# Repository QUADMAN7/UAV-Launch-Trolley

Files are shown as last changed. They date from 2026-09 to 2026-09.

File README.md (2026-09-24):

# IoT-Enabled UAV Launch Trolley


## Project Overview & Goal
This repository details the development of an automated ground support trolley engineered to launch gearless, fixed-wing Unmanned Aerial Vehicles (UAVs). The project originated from an operational constraint encountered on a custom aircraft I designed and manufactured in a previous project. Design trade-offs on that airframe resulted in higher wing loading than originally intended, requiring the 2.43 kg aircraft to achieve a high take-off airspeed of at least 18 m/s. Because the airframe utilizes a rear-pusher configuration spinning a large 13-inch propeller, hand launching was off-the-table due to the risk of propeller strikes to the operator and low-speed stalls. To eliminate these operational risks without adding parasitic weight or landing gear to the airframe itself, I engineered a launch trolley capable of safely accelerating the UAV to speed and actively dropping away the moment aerodynamic lift is achieved.

---
## System Architecture & Hardware
### Technical Specifications

| Subsystem | Component / Technology | Operational Role |
| :--- | :--- | :--- |
| **Control Unit** | ESP32 (Wi-Fi AP mode) | Real-time sensor polling, telemetry hosting, servo actuation |
| **Velocity Sensing** | Neodymium Magnet + Hall Effect Sensor | Wheel RPM, instantaneous velocity, distance, acceleration |
| **Arming Controls** | Toggle Switch / LED | Master safety arming input and visual status feedback |
| **Liftoff Detection** | Pad Limit Switch | Instantaneous weight-off-wheels trigger |
| **Clearance System** | Servo-latch + Rubber-tension Parallel Linkage | Folds support arms flat to allow clearance for 13" pusher prop |
| **Telemetry Interface** | ESP32 Access Point + Embedded Web Server | Live Web UI streaming speed and state data over Wi-Fi |

---

### Design and Iterations
To establish the optimal launch method for the aircraft, I began by conducting a trade-off study across several concept architectures. I evaluated bungee systems, launch rails, catapults, and various airframe-mounted landing gear options, including both fixed and jettison-able assemblies. Ultimately, I eliminated catapults, rails, and onboard landing gear because they either imposed weight and drag penalties on the airframe—which directly inflated the required take-off velocity—or introduced high mechanical complexity with an elevated risk of damaging the aircraft during separation. Selecting an external ground support trolley provided the best solution: it added zero flight mass to the aircraft, offered reusable launch capabilities without airframe fatigue, and delivered a simple, robust footprint for field operations.

The cart chassis was designed to use easily machinable materials. A structural plywood plank acts as the base to which everything is mounted. Atop this base is a parallel-motion linkage engineered to drop the airframe support cradles instantly upon lift-off. To ensure the linkage folds flat with minimal mechanical resistance, I integrated ball bearings into all primary pivot joints to eliminate binding. The linkage is held in its elevated position by a servo-operated claw controlled by the ESP32. Upon receiving a release command, the servo disengages the claw, allowing a pre-tensioned rubber band to snap the mechanism flat. Using an elastomeric element provided a rapid, high-reliability restoring force without the weight, complexity, or power draw of active motorized retraction. To maximize stability during ground roll, the cradle pads were custom-designed as exact negative moulds of the aircraft's lower fuselage, ensuring a snug, load-distributing fit.

Beneath the main chassis, the running gear consists of dual axles supported by four low-friction bearing blocks. Sizing the wheels required a careful balance between ground clearance and roll stability: they needed to be large enough to roll over runway imperfections, yet compact enough to keep the overall centre of gravity low and prevent tipping instabilities during high-speed acceleration on the take-off run. During the initial design phase, I considered adding an active steering system linked directly to the aircraft’s rudder control channel, however, after analysing the failure modes and mass budget, I chose to omit ground steering. Eliminating active steering hardware simplified the system architecture and saved critical weight whilst accepting the trade-off that an unsteerable cart is susceptible to heading drift due to runway bumps and differential wheel rolling resistance. That said, I made the optimistic assumption that the aircraft's rudder would provide sufficient control authority for straight tracking on adequately smooth runway surfaces.

---

### How It Was Built
The trolley was constructed using a hybrid material selection composed of 12mm plywood, 3D-printed PLA, flexible TPU, and lightweight 8mm aluminium tubing. A 12mm plywood board forms the chassis, serving as a flat, rigid structural base to anchor all mechanical linkages, axle blocks, and electronic subassemblies.

The majority of the functional components—including the parallel-motion linkage arms, wheel hubs, and bearing housings were additively manufactured using PLA. While PETG offers higher impact resistance, limitations of my 3D printer (specifically thermal warping on larger geometries) made PLA the more reliable choice for maintaining tight dimensional tolerances across the joint linkages. To complement the rigid PLA parts, flexible TPU was strategically applied where compliance and energy absorption were necessary. TPU was used for the tyres to dampen runway vibrations, for the bump-stop that catches the linkage when it snaps flat, and for the airframe support pads that conform to the aircraft's fuselage.

To span the support footprint of the aircraft without adding unnecessary rotating mass or printing oversized plastic parts, I used 8mm aluminium tubing for both the axles and the upper cradle support frame. Utilizing aluminium tubes provided a significantly stiffer, lighter, and simpler structural bridge than attempting to 3D print a massive PLA/TPU equivalent. The custom-moulded TPU support pads were permanently bonded to the 8mm aluminium bars using epoxy resin. The entire mechanical assembly is secured using M3 hardware, integrating heat-set brass inserts directly into the 3D-printed components to deliver robust, reusable threaded joints that withstand repeated operational loads.

Before final physical assembly, the embedded control hardware and sensor circuits were prototyped and validated on a breadboard. This allowed me to make sure everything worked as intended prior to mounting it all to the trolley.

---

### Electronics
To govern the real-time telemetry, safety interlocks, and mechanical release, the trolley utilizes a custom embedded system centred around an ESP32 microcontroller. Power management is handled by an onboard 9V battery paired with a DC-DC buck converter, stepping the voltage down to a regulated 5V rail to reliably power the microcontroller, sensors, and actuation hardware.

The sensing suite consists of two primary inputs designed to feed the onboard kinematics and state tracking logic. A Hall effect sensor tracks wheel rotations to calculate real-time ground speed, while a physical limit switch embedded beneath the support pads acts as a weight-off-wheels sensor to confirm whether the aircraft is actively sitting on the trolley or not. System actuation is intentionally streamlined to minimize power draw and weight, relying on a single analogue servo. When triggered by the ESP32's safety logic, this servo disengages the latching mechanism, allowing the parallel-motion linkage to collapse flat under the tension provided by the rubber band.

For field operation and ground crew safety, the human-machine interface incorporates a heavy-duty mechanical arming toggle switch, a visual status LED, and an audible piezo buzzer. Recognizing that bright outdoor sunlight and high-glare field environments can easily obscure visual LED feedback during launch operations, I integrated a buzzer that provides unambiguous audible confirmation when the trolley is armed. This dual-sensory confirmation guarantees that ground operators can definitively verify the system's state before initiating a high-speed take-off run.

---

### Firmware & Embedded Systems Overview

* **Non-Blocking Speed Tracking:** Uses hardware interrupts to measure microsecond pulse intervals from the Hall effect sensor. Speed calculations are mathematically filtered to minimise sensor noise, with a 0.5 second timeout to automatically clear stale speed readings when coming to a stop.
* **Off-Grid Telemetry Web Dashboard:** The ESP32 broadcasts a local Wi-Fi signal hosting a live HTML interface. Ground crew can connect via smartphone to view live speed, acceleration, and take-off distance without relying on external internet or ground control stations.
* **Fail-Safe Release Interlock:** To prevent accidental drops, the parallel linkage release servo will only trigger when three independent conditions are met simultaneously:
  1. The master arming switch is flipped ON (confirmed via status LED and audible buzzer).
  2. The cart reaches or exceeds the target 18m/s take-off speed threshold.
  3. The aircraft lifts off, un-weighting the cradle's physical limit switch.

> **Full Firmware Breakdown:** For a complete look at the state machines, filtering logic, and code structure, see the [Firmware Architecture Documentation](Firmware/README.md).

---

### Operational Flow Diagram

```text
[ Ground Acceleration Phase ]
  │  ├── Hall sensor measures wheel RPM -> ESP32 calculates velocity
  │  └── ESP32 streams live velocity, displacement and acceleration data to Web UI over Wi-Fi
  ▼
[ Lift-off Event (V_ground ≥ 18 m/s) ]
  │  ├── Aerodynamic lift removes 2.43 kg weight from cradle
  │  └── Support pad limit switch is in normally open position (Weight-Off-Wheels signal)
  ▼
[ Active Clearance Trigger ]
  │  ├── ESP32 receives limit switch signal
  │  ├── Release servo disengages support arm latch
  │  └── Rubber band folds linkages flat
  ▼
[ Safe Separation ]
     └── 13" pusher prop passes cleanly over folded cart
```
---
## Engineering Challenges & Solutions
**1. 13" Propeller Clearance:** After making many iterative sketches, I found that the most suitable way to solve the issue was to increase the clearance between the trolley and the UAV at the point of take-off. This solution offered a package that was smaller and, consequently, lighter than other ideas I explored. This has the benefit of being easier to transport and for the UAV to accelerate itself and the trolley more quickly (therefore using less runway). To come up with a system to increase the clearance between the UAV and the trolley support pads upon which the UAV sits, I researched different mechanical systems such as scissor lifts but decided to go with a parallel motion linkage as it was simpler and could quickly be actuated to go from its highest point to its lowest point.

**2. Sensor Saturation:** In my initial design of the wheel speed tracking system, I embedded eight evenly spaced neodymium magnets into the wheel hub to maximize velocity measurement resolution. During high-speed testing, however, I discovered that this high-density arrangement only functioned reliably at low speeds under 5 m/s. Beyond this threshold, the rapid rotational frequency overwhelmed the Hall effect sensor's frequency response. The sensor could no longer react quickly enough to detect the magnetic gaps between pulses, causing it to saturate and latch into a continuous detection state.

This physical saturation directly interacted with my firmware's safety logic. To prevent the system from holding a stale speed reading after coming to a complete stop, I had programmed a timeout mechanism that reset the calculated velocity to 0 m/s if no pulse interrupts were registered within a set time window. Consequently, when sensor saturation occurred at speed, the lack of toggling state transitions caused the code to interpret the continuous signal as a stopped cart, abruptly dropping the telemetry speed output to 0 m/s mid-run.

To resolve this sensor bandwidth issue, I modified the wheel hub to house only a single neodymium magnet, lowering the pulse frequency enough in the hopes that it would be able to accommodate take-off velocities up to 25 m/s. While this change successfully restored function for standard testing, a critical evaluation of the system suggests that at the higher end of the operational envelope (exceeding 15 to 18 m/s) the sensor may approach its hardware response limits once again due to the high RPM of the small wheels.

In evaluating future design iterations to eliminate this failure mode entirely, I analysed two potential engineering solutions. The first option—increasing the main wheel diameter to lower the rotational RPM—was ruled out because a larger wheel elevates the cart's centre of gravity, significantly increasing the risk of dynamic tip-over during high-speed acceleration runs. The superior engineering approach would be to integrate a secondary sensor wheel connected to the main axle via a mechanical gear reduction. This would allow the magnets to pass the Hall effect sensor at a lower, controlled frequency during high-speed runs while maintaining a low centre of gravity and preserving full signal integrity across the entire operational envelope.

**3. Premature Retraction**: I implemented a triple-condition safety interlock in the state machine logic in order to avoid a scenario where a bump on a runway causes the UAV to momentarily lift-off the support pads at low airspeeds, tricking the microcontroller into thinking the UAV has taken-off, leading to a high-speed prop strike while the drone was still on the cart, potentially damaging the UAV as well as the cart. The ESP32 strictly forbids servo actuation unless three conditions are met simultaneously:
  1. **Master Arm Switch:** The arm switch must be toggled ON. This also has the benefit of allowing you to setup the UAV on the cart without worrying that the cart might fold whilst on the bench
  2. **Weight-Off-Wheels Signal:** Limit switch state registers open.
  3. **Velocity Threshold Interlock:** Real-time Hall sensor speed readout confirms $V_{\text{ground}} \ge 18\text{ m/s}$ alongside a 100ms debouncing window.

---

## Conclusion
This instrumented ground support trolley successfully bridges the gap between high-speed aerodynamic constraints and safe launch logistics. By combining embedded C++ firmware, Hall-effect sensing, and active mechanical clearance linkages, the system replaces high-risk hand launches with a repeatable, telemetry-monitored ground take-off platform.

Although designed around a specific 2.43 kg fixed-wing SAR airframe, the modular mechatronic architecture serves as a scalable foundation for future Ground Support Equipment across higher-weight unmanned systems.

---
## Repository structure
```text

├── CAD/
│   └── Launch Trolley.step     # Full mechanical cart assembly
│
├── Firmware/
│   ├── Complete_System.ino     # Code
│   └── README.md     # Deep dive into code
│
├── Media/
│   └── README.md     # Pictures and renders of final product and iterative sketches
│
└── README.md
```

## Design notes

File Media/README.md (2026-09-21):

### This file contains pictures of Sketches, renders, the final product and a showcase of the web interface hosted by the ESP32




Launch_Trolley_2026-Sep-07_11-09-02AM-000_CustomizedView33224193533
Launch_Trolley_2026-Sep-07_11-10-29AM-000_CustomizedView13705926072
Launch_Trolley_2026-Sep-07_11-12-04AM-000_CustomizedView38185863168











### Showcase of Web interface hosted by the ESP32
https://github.com/user-attachments/assets/f3720539-ddbf-49d7-8c27-fad475daf408

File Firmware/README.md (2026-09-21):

# Firmware Architecture & Control Logic

## 1. System Intent & Engineering Strategy
The primary function of the trolley firmware is to provide real-time launch telemetry and govern the automated release mechanism for the UAV. To ensure safe, reliable operations in field environments, the software architecture was designed around three core principles:

1. **Non-blocking Telemetry:** Measure vehicle speed, displacement, and acceleration continuously without stopping the main control loop.
2. **Fail-Safe Safety Interlocks:** Prevent premature mechanical actuation through a combination of physical hardware states and firmware logic gates.
3. **Zero-Infrastructure Monitoring:** Broadcast live flight metrics directly to operators without relying on external Wi-Fi networks or bulky ground control equipment.

---

## 2. Telemetry & Signal Processing

### Interrupt-Driven Kinematics
To capture high-speed wheel rotations accurately, wheel pulse detection is handled via hardware interrupts (`IRAM_ATTR`). Measuring microsecond intervals (`micros()`) between pulse triggers provides higher accuracy than polling the pin in the main loop.

### Noise Mitigation & Filtering
Raw velocity calculations from small-diameter wheels are inherently prone to mechanical vibration and pulse jitter. To deliver stable control inputs and clean UI visualization, the firmware processes raw sensor signals through two stages:

* **Exponential Moving Average (EMA) Filter:** Smooths transient velocity spikes using a weighting factor ($\alpha = 0.2$). This prioritizes trend stability while retaining low latency for rapid acceleration runs.
* **Dynamic Clamping:** Physical acceleration values are clamped within physical bounds ($\pm 20\text{ m/s}^2$) to eliminate erroneous mathematical noise spikes during rapid signal state changes.
* **Zero-Speed Timeout:** To prevent stale telemetry output when the trolley stops, a $0.5\text{-second}$ pulse timeout automatically resets velocity to zero if no new magnet pulses are registered.

---

## 3. Safety Interlocks & Release State Machine

Accidental release of the parallel linkage during pre-flight handling poses a direct hazard to the airframe and ground crew. To eliminate single-point failures, mechanical release requires three independent conditions to be satisfied simultaneously:
``` text
[ Hardware Arm Switch: ON ] ──┐
├─► [ Logical AND Gate ] ──► [ Command Servo Release ]
[ Weight-Off-Wheels: HIGH ]  ──┤
│
[ Launch Speed >= 18 m/s ]   ──┘
```

1. **Master Physical Arming Switch:** Mechanically isolates the system. When disarmed, the servo is held rigidly at $190^\circ$ (latching the linkage), regardless of sensor inputs.
2. **Audible & Visual State Feedback:** Upon arming, the ESP32 drives an LED and fires a piezo buzzer tone to alert field operators.
3. **Automated Velocity Threshold:** The release servo ($0^\circ$) will only trigger once smoothed ground velocity meets or exceeds the minimum flight speed ($18\text{ m/s}$) AND the weight-off-wheels sensor indicates the aircraft is lifting.

Upon successful release, the firmware latches the current displacement value to permanently record the total ground roll distance required for take-off.

---

## 4. Off-Grid Field User Interface
To eliminate the need for heavy ground station laptops, the ESP32 acts as a standalone Wi-Fi network hosting a HTTP web server. 

* The server delivers a single lightweight HTML/JS dashboard to connected mobile devices.
* Kinematic state data (`displacement`, `velocity`, `acceleration`, `takeOffDistance`) are packaged as lightweight JSON text and served at a `/data` web address that the browser reads automatically
* Client-side JavaScript polls this endpoint asynchronously every $200\text{ ms}$, delivering real-time numerical visual readouts without triggering full page reloads.

---

## 5. Prototype Trade-Offs & Production Enhancements

As an initial functional prototype, the system successfully validated automated launch mechanics in bench testing. For future production iterations, before conducting a real world test, the following software enhancements are planned:

* **Non-Volatile Logging:** Integrate SD card logging to store historical run data locally for post-flight telemetry analysis.
* **Dynamic Speed Calibration:** Allow operators to adjust the threshold launch speed directly from the web interface prior to arming, eliminating the need to re-flash firmware for different airframes.

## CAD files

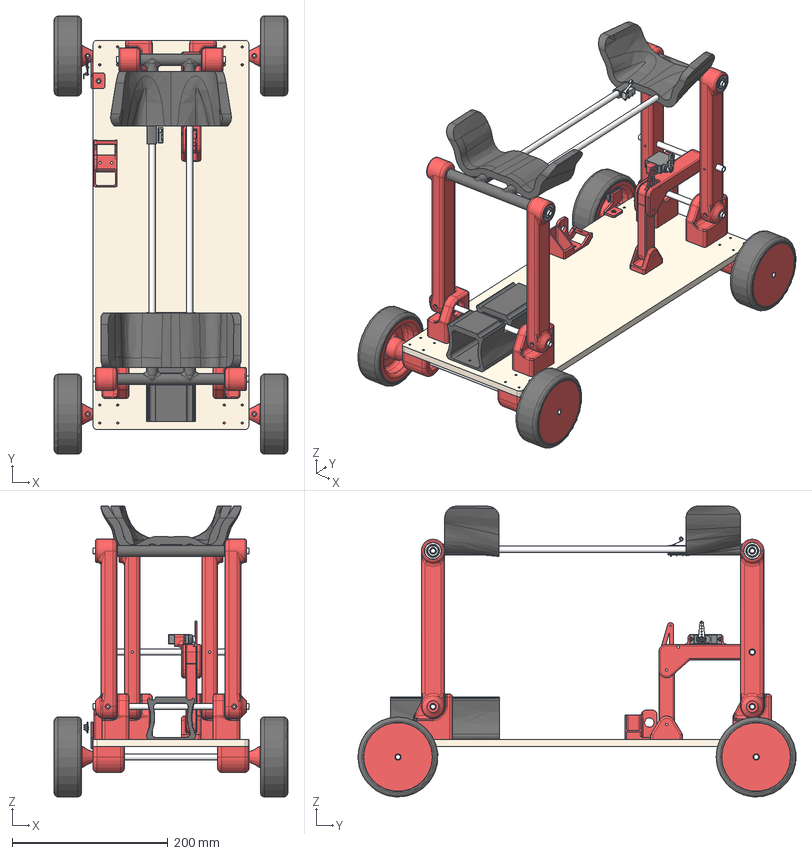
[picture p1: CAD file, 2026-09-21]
CAD/Launch Trolley.step
300.0 x 562.5 x 373.4 mm
Interface
2349K701_Permanently Lubricated Ball Bearing x 10
Arm 1
Base 1
Arm 2
Base 2
Arm 3
Base 3
Arm 4
Base 4
Aluminium Rod [R] (1)
Base
Servo Mount (1)
Claw
Wheels
2349K701_Permanently Lubricated Ball Bearing(Mirror)
7658K16_Subminiature Snap-Acting Switch
92095A287_Button Head Hex Drive Screw(Mirror)
Arm(Mirror)
9SENHMS
Hall Effect Sensor Mount
Switch Mount+Battery Tray

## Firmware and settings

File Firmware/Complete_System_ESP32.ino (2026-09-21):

#include <WiFi.h>
#include <WebServer.h>
#include <ESP32Servo.h>

// Hardware config
#define HALL_SENSOR_PIN 20  // Hall sensor pin
#define ARM_SWITCH_PIN 9    // Arm switch
#define ARM_LED_PIN 4       // Arm LED
#define BUTTON_PIN 5        // Momentary switch
#define SERVO_PIN 7         // Servo signal

const uint8_t NUM_MAGNETS = 1;
const float WHEEL_RADIUS = 0.1027 / 2.0; // meters
const float CIRCUMFERENCE = 2.0 * PI * WHEEL_RADIUS;

volatile unsigned long lastTime = 0;
volatile unsigned long period = 0;
volatile int hallCounter = 0;

float velocity = 0.0;
float displacement = 0.0;
float acceleration = 0.0;

float takeOffDistance = 0.0;
bool takeOffRecorded = false;

unsigned long prevMicros = 0;

const float LAUNCH_SPEED = 18;  // m/s launch speed threshold
const unsigned long VELOCITY_TIMEOUT_US = 500000; // 0.5 seconds timeout for velocity zero

bool systemArmed = false;
bool servoReleased = false; // True if servo moved to 0°
bool buttonPressed = false;

Servo myServo;

WebServer server(80);

// ISR for Hall sensor pulses
void IRAM_ATTR hallInterrupt() {
  unsigned long now = micros();
  unsigned long diff = now - lastTime;
  if (diff > 1000) { // debounce 1ms
    period = diff;
    lastTime = now;
    hallCounter++;
  }
}

// HTML page with telemetry and take-off distance display
const char index_html[] PROGMEM = R"rawliteral(
<!DOCTYPE html>
<html>
<head>
  <title>VEHICLE TELEMETRY</title>
  <meta charset="UTF-8">
  <style>
    body {
      font-family: Arial, sans-serif;
      text-align: center;
    }
    h1 {
      font-family: Arial, sans-serif;
      font-size: 3em;
      color: black;
      margin-bottom: 30px;
    }
    table {
      margin: 0 auto;
      border-collapse: collapse;
      font-weight: bold;
    }
    table, th, td {
      border: 2px solid black;
      padding: 15px 30px;
    }
    th {
      font-size: 1.2em;
    }
    td {
      font-size: 1em;
    }
    #velocity {
      font-size: 2em;
      color: red;
    }
    .units {
      font-size: 0.7em;
      font-weight: normal;
      margin-left: 4px;
    }
    button {
      font-size: 1em;
      padding: 10px 25px;
      margin-top: 30px;
      cursor: pointer;
    }
    #takeoffContainer {
      font-size: 1.5em;
      margin-top: 20px;
    }
    .flashing {
      animation: flashRedBlack 0.5s infinite;
    }
    @keyframes flashRedBlack {
      0%, 100% { color: red; }
      50% { color: black; }
    }
  </style>
</head>
<body>
  <h1>VEHICLE TELEMETRY</h1>
  <table>
    <tr>
      <th>Displacement<span class="units">m</span></th>
      <th>Velocity<span class="units">m/s</span></th>
      <th>Acceleration<span class="units">m/s²</span></th>
    </tr>
    <tr>
      <td><span id="displacement">0.00</span></td>
      <td><span id="velocity">0.00</span></td>
      <td><span id="acceleration">0.00</span></td>
    </tr>
  </table>

  <div id="takeoffContainer"></div>

  <button onclick="resetTelemetry()">Reset Telemetry</button>

  <script>
    let flashTimeout;

    async function fetchData() {
      try {
        const res = await fetch('/data');
        const data = await res.json();

        document.getElementById('displacement').textContent = data.displacement.toFixed(2);
        document.getElementById('velocity').textContent = data.velocity.toFixed(2);
        document.getElementById('acceleration').textContent = data.acceleration.toFixed(2);

        updateTakeOffDistance(data);
      } catch (e) {
        console.error('Error fetching data:', e);
      }
    }

    function updateTakeOffDistance(data) {
      const container = document.getElementById("takeoffContainer");
      if (data.takeOffDistance > 0) {
        container.textContent = `Take-Off Distance: ${data.takeOffDistance.toFixed(2)} m`;
        if (data.flashing) {
          container.classList.add("flashing");
          if (flashTimeout) clearTimeout(flashTimeout);
          flashTimeout = setTimeout(() => {
            container.classList.remove("flashing");
          }, 3000);
        }
      } else {
        container.textContent = '';
        container.classList.remove("flashing");
      }
    }

    async function resetTelemetry() {
      await fetch('/reset');
    }

    setInterval(fetchData, 200);
  </script>
</body>
</html>
)rawliteral";


void setup() {
  Serial.begin(115200);

  pinMode(HALL_SENSOR_PIN, INPUT_PULLUP);
  pinMode(ARM_SWITCH_PIN, INPUT_PULLUP);
  pinMode(BUTTON_PIN, INPUT_PULLUP);
  pinMode(ARM_LED_PIN, OUTPUT);

  attachInterrupt(digitalPinToInterrupt(HALL_SENSOR_PIN), hallInterrupt, RISING);

  WiFi.softAP("ESP_Telemetry", "God_Speed");
  Serial.println("WiFi AP started: ESP_Telemetry | Password: God_Speed");
  Serial.println("Go to http://192.168.4.1");

  server.on("/", []() {
    server.send_P(200, "text/html", index_html);
  });

  server.on("/data", []() {
    String json = "{\"displacement\":";
    json += displacement;
    json += ",\"velocity\":";
    json += velocity;
    json += ",\"acceleration\":";
    json += acceleration;
    json += ",\"takeOffDistance\":";
    json += takeOffDistance;
    json += ",\"flashing\":";
    json += (servoReleased ? "true" : "false");
    json += "}";
    server.send(200, "application/json", json);
  });

  server.on("/reset", []() {
    displacement = 0.0;
    velocity = 0.0;
    acceleration = 0.0;
    takeOffDistance = 0.0;
    takeOffRecorded = false;
    servoReleased = false;
    Serial.println("Telemetry Reset");
    server.send(200, "text/plain", "Telemetry Reset");
  });

  server.begin();

  myServo.attach(SERVO_PIN, 500, 2500);
  myServo.write(190);  // Default servo position (Locked)
}

#define ACCELERATION_CLAMP 20.0  // Max abs acceleration allowed (m/s²)

void loop() {
  server.handleClient();

  static int lastHallCount = 0;
  static float prevVelocity = 0.0;
  static float smoothedVelocity = 0.0;

  if (hallCounter != lastHallCount) {
    Serial.printf("Interrupts: %d, period (us): %lu\n", hallCounter, period);
    lastHallCount = hallCounter;
  }

  unsigned long currentMicros = micros();
  float dt = (currentMicros - prevMicros) / 1e6;

  if (dt < 0.0001) return; // ignore unrealistically small dt 

  if (dt > 0.001) {
    prevMicros = currentMicros;

    unsigned long timeSinceLastPulse = currentMicros - lastTime;

    if (timeSinceLastPulse > VELOCITY_TIMEOUT_US) { // Timeout => wheel stopped
      velocity = 0.0;
    } else if (period > 0 && period < 1000000) { // ignore period > 1s
      float timeForOneRevolution = (period * NUM_MAGNETS) / 1e6;
      velocity = CIRCUMFERENCE / timeForOneRevolution;
    } else {
      velocity = 0.0;
    }

    const float alpha = 0.2;
    smoothedVelocity = alpha * velocity + (1 - alpha) * smoothedVelocity;

    // Only integrate displacement if velocity > 0 to prevent drift
    if (smoothedVelocity > 0.01) {
      displacement += smoothedVelocity * dt;
    }

    float deltaV = smoothedVelocity - prevVelocity;
    float accel = deltaV / dt;

    if (accel > ACCELERATION_CLAMP) accel = ACCELERATION_CLAMP;
    else if (accel < -ACCELERATION_CLAMP) accel = -ACCELERATION_CLAMP;

    acceleration = accel;
    prevVelocity = smoothedVelocity;
  }

  // Read arm switch and LED
  systemArmed = (digitalRead(ARM_SWITCH_PIN) == LOW);
  digitalWrite(ARM_LED_PIN, systemArmed ? HIGH : LOW);

  // Read momentary button (active LOW)
  bool currentButtonPressed = (digitalRead(BUTTON_PIN) == LOW);

  // Logic for servo and takeOffDistance:
  // Servo moves to 0 degrees ONLY if:
  // - systemArmed == true
  // - launch speed reached
  // - momentary button released (NOT pressed)
  // Also servo should remain at 0° until system disarmed.

  // Detect button release event
  static bool lastButtonState = false;

  // On button release
  if (lastButtonState && !currentButtonPressed) {
    buttonPressed = false;
    // Check conditions for servo release and take-off distance
    if (systemArmed && smoothedVelocity >= LAUNCH_SPEED && !servoReleased && !takeOffRecorded) {
      myServo.write(0);
      servoReleased = true;
      takeOffDistance = displacement;
      takeOffRecorded = true;
      Serial.println("Servo Released and Take-Off Distance recorded");
    }
  }

  // Update button pressed state
  if (!lastButtonState && currentButtonPressed) {
    buttonPressed = true;
  }
  lastButtonState = currentButtonPressed;

  // If disarmed, servo returns to 190°
  if (!systemArmed && servoReleased) {
    myServo.write(190);
    servoReleased = false;
    takeOffRecorded = false;
    takeOffDistance = 0.0;
    Serial.println("System disarmed, servo reset");
  }
}
